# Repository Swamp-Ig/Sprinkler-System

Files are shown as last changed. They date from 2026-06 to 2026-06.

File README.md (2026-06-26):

# 6-Zone WiFi Sprinkler Controller

A custom PCB for controlling up to six 24 VAC irrigation solenoid valves via WiFi, using an ESP32 and ESPHome with native Home Assistant integration.

## Features

- **6 independent zones** — each zone switches a 24 VAC solenoid valve via an Omron G5LE-1 relay
- **WiFi control** — ESP32-WROOM-32U with external U.FL antenna connector
- **Home Assistant integration** — ESPHome firmware; zones appear as switch entities
- **Onboard power supply** — HLK-PM01 AC-DC module (mains → 5 V); AMS1117-3.3 regulator (5 V → 3.3 V for ESP32)
- **Relay isolation** — ULN2803A Darlington array isolates ESP32 GPIOs from relay coil drive current
- **Protected design** — varistors on each zone output and across the mains input and transformer primary (RV1/RV2), time-delay fuses on the mains and 24 VAC supplies, per-zone RC snubbers, and an optocoupler-isolated 24 VAC rail sense

## ⚠️ Safety

> **This board carries mains voltage (Line and Neutral) on the PCB.**  
> The HLK-PM01 module is connected directly to mains. The 24 VAC solenoid rail is transformer-isolated but still carries AC voltage.

- Do **not** touch or probe the board while it is powered.
- The enclosure **must** be non-conductive and fully closed before applying mains power.
- All mains wiring must comply with local electrical codes. Use appropriately rated cable and terminals.
- The external transformer must be safety-rated (UL, CE, or equivalent) for your locale.
- Replace fuses only with the specified ratings — see the BOM below.

See [Assembly Notes](docs/assembly.md) for enclosure requirements and conformal coating instructions.

## How It Works

The controller has three linked paths: logic power, 24 VAC valve power, and relay control.

**Logic power:** Mains → F1 → HLK-PM01 → 5 V → AMS1117-3.3 → 3.3 V → ESP32 + logic

**24 VAC path:** Mains → F1 → G3MB-202P SSR (K1, GPIO16) → J2 → external transformer → J3 → F2 → zone relays (K20–K25) → solenoids

**Control:** ESP32 GPIO17–23 → ULN2803A → relay coils K20–K25 → zone outputs J20–J25

When a zone is activated, the ESP32 first enables the 24 VAC rail (K1), then drives the selected relay through the ULN2803A. The ULN2803A acts as a low-side driver, keeping ESP32 GPIO current low while switching the 24 VAC solenoid load through the relay contacts.

## Bill of Materials

| Ref | Component | Value / Part No. | Notes |
|-----|---|---|---|
| U4 | ESP32 module | ESP32-WROOM-32U | External antenna (U.FL) |
| U3 | AC-DC module | HLK-PM01 | 100–240 VAC in, 5 V / 600 mA out |
| U1 | LDO regulator | AMS1117-3.3 | SOT-223 |
| U2 | Optocoupler | EL817 | Isolates the 24 VAC rail sense |
| U5 | Darlington array | ULN2803A | SOIC-18 |
| K1 | Solid-state relay | Omron G3MB-202P | Gates the 24 VAC solenoid rail (GPIO16) |
| K20–K25 | Relay ×6 | Omron G5LE-1 | SPDT, 5 V coil, 10 A / 250 VAC contacts |
| RV20–RV25 | Varistor ×6 | 68 V | Surge protection, one per zone output |
| RV1 | Varistor | 10D471K (275 VAC) | Across mains L–N input, after F1 |
| RV2 | Varistor | 10D471K (275 VAC) | Across K1 SSR output / transformer primary |
| F1 | Fuse | **T1A** (time-delay) | Mains supply — slow-blow for transformer/HLK inrush |
| F2 | Fuse | **T2A** (time-delay) | 24 VAC supply — slow-blow for solenoid inrush |
| D1 | Diode | 1N4148 (0805) | 24 VAC rail sense |
| C5 | Capacitor | 220 µF / ≥10 V | 5 V rail bulk reservoir (THT radial) |
| C1, C7 | SMD capacitors | 10 µF | Supply filtering |
| C2, C3 | SMD capacitors | 22 µF | Supply filtering / sense |
| C4, C6, C20–C25 | SMD capacitors | 100 nF | ESP32 VDD (C4), EN reset (C6), zone snubbers (C20–C25) |
| R1, R3, R5, R6, R8, R10, R11 | SMD resistors | 10 kΩ | Sense, pull-ups, pull-downs |
| R2, R9, R12–R14 | SMD resistors | 4.7 kΩ | Sense, LED series, I²C pull-ups |
| R4, R7 | SMD resistors | 470 Ω | EN/BOOT switch series |
| R20–R25 | SMD resistors | 100 Ω | Zone snubber series |
| LED1, LED2 | LED ×2 | 0805 | IO2 status / power |
| SW1, SW2 | Tactile switch ×2 | — | EN (reset) / BOOT |
| J1 | Screw terminal | Phoenix PT 1,5/3-5.0 (3-pin, 5.0 mm) | Mains input — must be mains-rated |
| J2 | Screw terminal | 2-pin, 5.0 mm | 240 VAC output to transformer primary |
| J3, J20–J25 | Pluggable terminal ×7 | KF2EDG-style, 2-pin | 24 VAC — J3 transformer in, J20–J25 zone outputs |
| XFMR | Transformer (external) | 240 VAC → 24 VAC, ≥50 VA, safety-rated | Size for zones × ~8 VA each |

See [`manufacturing/bom/bom.csv`](manufacturing/bom/bom.csv) for the full BOM with quantities and footprints.

## Reference

- [Wiring & GPIO](docs/wiring.md) — connector pinouts and GPIO assignments
- [ESPHome Configuration](docs/esphome.md) — full firmware config, fault detection, and optional pump relay setup
- [Assembly Notes](docs/assembly.md) — step-by-step build and commissioning guide

## Project Structure

```
Sprinkler System.kicad_pro    ← KiCad project file
Sprinkler System.kicad_sch    ← Schematic
Sprinkler System.kicad_pcb    ← PCB layout
Sprinkler System.pretty/      ← Custom footprints and 3D models
symbols/                       ← Custom symbol library (G3MB-202P)
manufacturing/
  gerbers/                     ← Gerber files for PCB fabrication
  drill/                       ← Excellon drill files
  pos/                         ← Pick-and-place centroid files
  bom/bom.csv                  ← Bill of materials
docs/
  schematic.pdf                ← Schematic PDF
  pcb.pdf                      ← PCB layer PDF
  board.step                   ← 3D STEP model
  wiring.md                    ← Connector and GPIO reference
  esphome.md                   ← ESPHome firmware configuration
  assembly.md                  ← Build and commissioning guide
.githooks/pre-commit           ← Auto-exports fabrication outputs on commit
setup / setup.ps1              ← One-time dev environment setup
release / release.ps1          ← Tag a release version
```

## Developing

### First-time setup

```powershell
.\setup.ps1
```

Configures the git hook path and verifies `kicad-cli` is available. Use `./setup` in Git Bash / WSL.

### Fabrication exports

Gerbers, drill files, PDFs, BOM, netlist, and STEP are regenerated automatically by the pre-commit hook whenever `Sprinkler System.kicad_pcb` or `Sprinkler System.kicad_sch` are staged. No manual export step is needed.

Run DRC and ERC from within KiCad before committing — fix all errors before submitting to a board house.

### Releasing

```powershell
.\release.ps1 v1.1.0
```

Stamps the schematic and PCB title blocks with the version and date, commits (triggering a fresh fabrication export), and creates the git tag. Use `./release v1.1.0` in Git Bash / WSL. Then push:

```powershell
git push && git push origin v1.1.0
```

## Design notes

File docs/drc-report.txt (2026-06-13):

** Drc report for Sprinkler System.kicad_pcb **
** Created on 2026-06-13T18:46:50 **
** Report includes: Errors, Warnings **

** Found 0 DRC violations **

** Found 0 unconnected pads **

** Found 0 Footprint errors **

** Ignored checks **
    - None

** End of Report **

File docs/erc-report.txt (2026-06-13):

ERC report (2026-06-13T18:46:48, Encoding UTF8)
Report includes: Errors, Warnings

***** Sheet /

 ** ERC messages: 0  Errors 0  Warnings 0

 ** Ignored checks:
    - Input Power pin not driven by any Output Power pins
    - Four connection points are joined together
    - SPICE model issue
    - Symbol doesn't match copy in library
    - Footprint link issue

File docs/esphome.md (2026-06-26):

# ESPHome Configuration

Flash the ESP32 via the J5 (UART0) header before installing the board in an enclosure. Add your secrets to `secrets.yaml`.

## Base Configuration (6 zones, no pump)

```yaml
esphome:
  name: sprinkler
  friendly_name: Sprinkler Controller

esp32:
  board: esp32dev

wifi:
  ssid: !secret wifi_ssid
  password: !secret wifi_password

api:
  encryption:
    key: !secret api_key

ota:
  - platform: esphome
    password: !secret ota_password

i2c:
  sda: GPIO5
  scl: GPIO4
  scan: true

globals:
  - id: fault_latched
    type: bool
    restore_value: true
    initial_value: 'false'

switch:
  - platform: gpio
    id: supply_24v
    pin: GPIO16
    name: "24V Supply"
    internal: true        # managed by sprinkler component via valve_open_switch
    restore_mode: ALWAYS_OFF

  - platform: gpio
    id: zone_0
    pin: GPIO17
    name: "Zone 0"
    internal: true
    restore_mode: ALWAYS_OFF

  - platform: gpio
    id: zone_1
    pin: GPIO18
    name: "Zone 1"
    internal: true
    restore_mode: ALWAYS_OFF

  - platform: gpio
    id: zone_2
    pin: GPIO19
    name: "Zone 2"
    internal: true
    restore_mode: ALWAYS_OFF

  - platform: gpio
    id: zone_3
    pin: GPIO21
    name: "Zone 3"
    internal: true
    restore_mode: ALWAYS_OFF

  - platform: gpio
    id: zone_4
    pin: GPIO22
    name: "Zone 4"
    internal: true
    restore_mode: ALWAYS_OFF

  - platform: gpio
    id: zone_5
    pin: GPIO23
    name: "Zone 5"
    internal: true
    restore_mode: ALWAYS_OFF

sprinkler:
  - id: sprinkler
    main_switch: "Sprinkler System"
    auto_advance: true
    valve_open_switch: supply_24v    # turns 24 VAC rail on/off automatically
    valves:
      - valve_switch: zone_0
        enable_switch: "Enable Zone 0"
        run_duration: 300s
        name: "Zone 0"
      - valve_switch: zone_1
        enable_switch: "Enable Zone 1"
        run_duration: 300s
        name: "Zone 1"
      - valve_switch: zone_2
        enable_switch: "Enable Zone 2"
        run_duration: 300s
        name: "Zone 2"
      - valve_switch: zone_3
        enable_switch: "Enable Zone 3"
        run_duration: 300s
        name: "Zone 3"
      - valve_switch: zone_4
        enable_switch: "Enable Zone 4"
        run_duration: 300s
        name: "Zone 4"
      - valve_switch: zone_5
        enable_switch: "Enable Zone 5"
        run_duration: 300s
        name: "Zone 5"

button:
  - platform: template
    name: "Reset 24V Fault"
    entity_category: config
    on_press:
      - globals.set:
          id: fault_latched
          value: 'false'

binary_sensor:
  - platform: gpio
    name: "Button 0"
    pin:
      number: GPIO34
      mode: INPUT         # input-only pin — external 10k pull-down sets idle LOW
      inverted: false   # active-HIGH — button pulls to +3.3 V, 10k pull-down idles LOW
    id: button_0

  - platform: gpio
    name: "Button 1"
    pin:
      number: GPIO35
      mode: INPUT         # input-only pin — external 10k pull-down sets idle LOW
      inverted: false
    id: button_1

  - platform: gpio
    name: "Button 2"
    pin:
      number: GPIO32
      mode: INPUT
      inverted: false
    id: button_2

  - platform: gpio
    name: "Button 3"
    pin:
      number: GPIO33
      mode: INPUT
      inverted: false
    id: button_3

  - platform: gpio
    name: "24V Present"
    pin:
      number: GPIO25
      mode: INPUT
    id: sens_24v
    device_class: power
    entity_category: diagnostic

  - platform: template
    name: "24V Fault"
    id: fault_24v
    device_class: problem
    filters:
      - delayed_on: 1s    # allow transformer + RC filter to charge before flagging fault
    lambda: |-
      return id(supply_24v).state && !id(sens_24v).state;
    on_press:
      then:
        - globals.set:
            id: fault_latched
            value: 'true'
        - sprinkler.stop: sprinkler

  - platform: template
    name: "24V Fault Latched"
    id: fault_latched_sensor
    device_class: problem
    entity_category: diagnostic
    lambda: 'return id(fault_latched);'

# Stop the sprinkler immediately if it is started while a fault is latched
interval:
  - interval: 500ms
    then:
      - if:
          condition:
            lambda: 'return id(fault_latched) && id(sprinkler).is_running();'
          then:
            - sprinkler.stop: sprinkler
```

`restore_mode: ALWAYS_OFF` ensures all outputs are off on boot or after a power failure — valves never left open unintentionally.

The zone GPIO switches are marked `internal: true` so they don't appear as individual entities in Home Assistant — the `sprinkler` component exposes them as named valves instead. The **24V Supply** switch is also internal; `valve_open_switch: supply_24v` tells ESPHome to energise K1 (the 24 VAC SSR) automatically when the first valve opens and cut it after the last valve closes.

Adjust `run_duration` per zone as needed.

---

## 24 VAC Fault Detection

GPIO25 reads the `Sens_24V` net, driven by an **EL817 optocoupler (U2)** that isolates the logic from the 24 VAC rail. On the rail side, D1 (1N4148) half-wave rectifies the 24 VAC and R1 (10 kΩ) limits the EL817 LED current. On the logic side the EL817 transistor pulls `Sens_24V` toward 3.3 V, with R2 (4.7 kΩ) and C3 (22 µF) forming the load and smoothing filter. When the rail is live the pin reads HIGH; when F2 blows or the transformer is absent, C3 discharges through R2 and the pin falls to LOW within a few hundred milliseconds.

**Fault behaviour**: when `supply_24v` is `ON` but `sens_24v` is `OFF`, the `24V Fault` sensor fires. This latches the `fault_latched` global, immediately stops the sprinkler, and the 500 ms interval prevents it from restarting. The latch persists across power cycles (`restore_value: true`).

**To clear**: press the **Reset 24V Fault** button in Home Assistant (or via the ESPHome API) after the underlying cause is fixed (e.g. replace F2). Add a Home Assistant automation on `fault_latched_sensor` to alert when a fault is detected.

---

## Optional: Pump Relay

Zone 0 (J20 / GPIO17 / K20) can be repurposed as a pump relay, giving 5 irrigation zones (Zones 1–5) plus a pump. This is useful when a booster pump or pump start relay is needed to maintain pressure.

Both the 24V supply (K1 SSR) and the pump relay need to be active whenever a valve runs. A template switch combines them as the single `valve_open_switch`. Replace the `valve_open_switch` and `valves` sections as follows:

```yaml
switch:
  # zone_0 becomes the pump relay
  - platform: gpio
    id: pump_relay
    pin: GPIO17
    name: "Pump"
    internal: true
    restore_mode: ALWAYS_OFF

  # Template switch enables both 24V supply and pump relay together
  - platform: template
    id: valve_master
    optimistic: true
    turn_on_action:
      - switch.turn_on: supply_24v
      - switch.turn_on: pump_relay
    turn_off_action:
      - switch.turn_off: pump_relay
      - switch.turn_off: supply_24v

  # supply_24v and zone_1–zone_5 unchanged

sprinkler:
  - id: sprinkler
    main_switch: "Sprinkler System"
    auto_advance: true
    valve_open_switch: valve_master   # enables both 24V rail and pump
    valves:
      # zone_0 removed — now the pump relay
      - valve_switch: zone_1
        enable_switch: "Enable Zone 1"
        run_duration: 300s
        name: "Zone 1"
      # ... zone_2 through zone_5
```

For precise pump start/stop delays (to control sequencing and water hammer), see the [ESPHome Sprinkler Controller documentation](https://esphome.io/components/sprinkler.html).

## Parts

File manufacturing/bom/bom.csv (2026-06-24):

Refs | Value | Footprint | Qty | DNP
C1 | 10u | Capacitor_SMD:C_0805_2012Metric_Pad1.18x1.45mm_HandSolder | 1
C2 | 22u | Capacitor_SMD:C_0805_2012Metric_Pad1.18x1.45mm_HandSolder | 1
C3 | 22u | Capacitor_SMD:C_0805_2012Metric_Pad1.18x1.45mm_HandSolder | 1
C4 | 100n | Capacitor_SMD:C_0805_2012Metric_Pad1.18x1.45mm_HandSolder | 1
C5 | 220u | Capacitor_THT:CP_Radial_D6.3mm_P2.50mm | 1
C6 | 100n | Capacitor_SMD:C_0805_2012Metric_Pad1.18x1.45mm_HandSolder | 1
C7 | 10u | Capacitor_SMD:C_0805_2012Metric_Pad1.18x1.45mm_HandSolder | 1
C20 | 100n | Capacitor_SMD:C_0805_2012Metric_Pad1.18x1.45mm_HandSolder | 1
C21 | 100n | Capacitor_SMD:C_0805_2012Metric_Pad1.18x1.45mm_HandSolder | 1
C22 | 100n | Capacitor_SMD:C_0805_2012Metric_Pad1.18x1.45mm_HandSolder | 1
C23 | 100n | Capacitor_SMD:C_0805_2012Metric_Pad1.18x1.45mm_HandSolder | 1
C24 | 100n | Capacitor_SMD:C_0805_2012Metric_Pad1.18x1.45mm_HandSolder | 1
C25 | 100n | Capacitor_SMD:C_0805_2012Metric_Pad1.18x1.45mm_HandSolder | 1
D1 | 1N4148 | Diode_SMD:D_0805_2012Metric_Pad1.15x1.40mm_HandSolder | 1
F1 | T1A | Sprinkler System:Fuseholder_5x20mm_15mm_Pins | 1
F2 | T2A | Sprinkler System:Fuseholder_5x20mm_15mm_Pins | 1
J1 | Main_Supply | TerminalBlock_Phoenix:TerminalBlock_Phoenix_PT-1,5-3-5.0-H_1x03_P5.00mm_Horizontal | 1
J2 | XFMR_Out | TerminalBlock_Phoenix:TerminalBlock_Phoenix_PT-1,5-2-5.0-H_1x02_P5.00mm_Horizontal | 1
J3 | XFMR_In | Connector_Phoenix_MC:PhoenixContact_MC_1,5_2-G-3.81_1x02_P3.81mm_Horizontal | 1
J4 | Conn_Button | Connector_JST:JST_XH_B6B-XH-A_1x06_P2.50mm_Vertical | 1
J5 | UART0 | Connector_JST:JST_XH_B4B-XH-A_1x04_P2.50mm_Vertical | 1
J6 | I2C | Connector_JST:JST_XH_B4B-XH-A_1x04_P2.50mm_Vertical | 1
J20 | Station_0 | Connector_Phoenix_MC:PhoenixContact_MC_1,5_2-G-3.81_1x02_P3.81mm_Horizontal | 1
J21 | Station_1 | Connector_Phoenix_MC:PhoenixContact_MC_1,5_2-G-3.81_1x02_P3.81mm_Horizontal | 1
J22 | Station_2 | Connector_Phoenix_MC:PhoenixContact_MC_1,5_2-G-3.81_1x02_P3.81mm_Horizontal | 1
J23 | Station_3 | Connector_Phoenix_MC:PhoenixContact_MC_1,5_2-G-3.81_1x02_P3.81mm_Horizontal | 1
J24 | Station_4 | Connector_Phoenix_MC:PhoenixContact_MC_1,5_2-G-3.81_1x02_P3.81mm_Horizontal | 1
J25 | Station_5 | Connector_Phoenix_MC:PhoenixContact_MC_1,5_2-G-3.81_1x02_P3.81mm_Horizontal | 1
JP1 | I2C_VCC | Jumper:SolderJumper-3_P1.3mm_Bridged12_RoundedPad1.0x1.5mm_NumberLabels | 1
K1 | G3MB-202P | Sprinkler System:RELAY_G3MB-202P | 1
K20 | G5LE-1-DC5 | Relay_THT:Relay_SPDT_Omron-G5LE-1 | 1
K21 | G5LE-1-DC5 | Relay_THT:Relay_SPDT_Omron-G5LE-1 | 1
K22 | G5LE-1-DC5 | Relay_THT:Relay_SPDT_Omron-G5LE-1 | 1
K23 | G5LE-1-DC5 | Relay_THT:Relay_SPDT_Omron-G5LE-1 | 1
K24 | G5LE-1-DC5 | Relay_THT:Relay_SPDT_Omron-G5LE-1 | 1
K25 | G5LE-1-DC5 | Relay_THT:Relay_SPDT_Omron-G5LE-1 | 1
LED1 | IO2 | LED_SMD:LED_0805_2012Metric_Pad1.15x1.40mm_HandSolder | 1
LED2 | PWR | LED_SMD:LED_0805_2012Metric_Pad1.15x1.40mm_HandSolder | 1
R1 | 10k | Resistor_SMD:R_0805_2012Metric_Pad1.20x1.40mm_HandSolder | 1
R2 | 4k7 | Resistor_SMD:R_0805_2012Metric_Pad1.20x1.40mm_HandSolder | 1
R3 | 10k | Resistor_SMD:R_0805_2012Metric_Pad1.20x1.40mm_HandSolder | 1
R4 | 470 | Resistor_SMD:R_0805_2012Metric_Pad1.20x1.40mm_HandSolder | 1
R5 | 10k | Resistor_SMD:R_0805_2012Metric_Pad1.20x1.40mm_HandSolder | 1
R6 | 10k | Resistor_SMD:R_0805_2012Metric_Pad1.20x1.40mm_HandSolder | 1
R7 | 470 | Resistor_SMD:R_0805_2012Metric_Pad1.20x1.40mm_HandSolder | 1
R8 | 10k | Resistor_SMD:R_0805_2012Metric_Pad1.20x1.40mm_HandSolder | 1
R9 | 4k7 | Resistor_SMD:R_0805_2012Metric_Pad1.20x1.40mm_HandSolder | 1
R10 | 10k | Resistor_SMD:R_0805_2012Metric_Pad1.20x1.40mm_HandSolder | 1
R11 | 10k | Resistor_SMD:R_0805_2012Metric_Pad1.20x1.40mm_HandSolder | 1
R12 | 4k7 | Resistor_SMD:R_0805_2012Metric_Pad1.20x1.40mm_HandSolder | 1
R13 | 4k7 | Resistor_SMD:R_0805_2012Metric_Pad1.20x1.40mm_HandSolder | 1
R14 | 4k7 | Resistor_SMD:R_0805_2012Metric_Pad1.20x1.40mm_HandSolder | 1
R20 | 100 | Resistor_SMD:R_0805_2012Metric_Pad1.20x1.40mm_HandSolder | 1
R21 | 100 | Resistor_SMD:R_0805_2012Metric_Pad1.20x1.40mm_HandSolder | 1
R22 | 100 | Resistor_SMD:R_0805_2012Metric_Pad1.20x1.40mm_HandSolder | 1
R23 | 100 | Resistor_SMD:R_0805_2012Metric_Pad1.20x1.40mm_HandSolder | 1
R24 | 100 | Resistor_SMD:R_0805_2012Metric_Pad1.20x1.40mm_HandSolder | 1
R25 | 100 | Resistor_SMD:R_0805_2012Metric_Pad1.20x1.40mm_HandSolder | 1
RV1 | 10D471K | Varistor:RV_Disc_D12mm_W4mm_P7.5mm | 1
RV2 | 10D471K | Varistor:RV_Disc_D12mm_W4mm_P7.5mm | 1
RV20 | 68V | Varistor:RV_Disc_D15.5mm_W5.4mm_P7.5mm | 1
RV21 | 68V | Varistor:RV_Disc_D15.5mm_W5.4mm_P7.5mm | 1
RV22 | 68V | Varistor:RV_Disc_D15.5mm_W5.4mm_P7.5mm | 1
RV23 | 68V | Varistor:RV_Disc_D15.5mm_W5.4mm_P7.5mm | 1
RV24 | 68V | Varistor:RV_Disc_D15.5mm_W5.4mm_P7.5mm | 1
RV25 | 68V | Varistor:RV_Disc_D15.5mm_W5.4mm_P7.5mm | 1
SW1 | EN | Button_Switch_SMD:SW_Push_SPST_NO_Alps_SKRK | 1
SW2 | BOOT | Button_Switch_SMD:SW_Push_SPST_NO_Alps_SKRK | 1
TP1 | Gnd | TestPoint:TestPoint_Pad_D1.5mm | 1
TP2 | 5V | TestPoint:TestPoint_Pad_D1.5mm | 1
TP3 | 3v3 | TestPoint:TestPoint_Pad_D1.5mm | 1
U1 | AMS1117-3.3 | Package_TO_SOT_SMD:SOT-223-3_TabPin2 | 1
U2 | EL817 | Package_SO:SOP-4_3.8x4.1mm_P2.54mm | 1
U3 | HLK-PM01 | Converter_ACDC:Converter_ACDC_Hi-Link_HLK-PMxx | 1
U4 | ESP32-WROOM-32U | RF_Module:ESP32-WROOM-32U | 1
U5 | ULN2803A | Package_SO:SOIC-18W_7.5x11.6mm_P1.27mm | 1

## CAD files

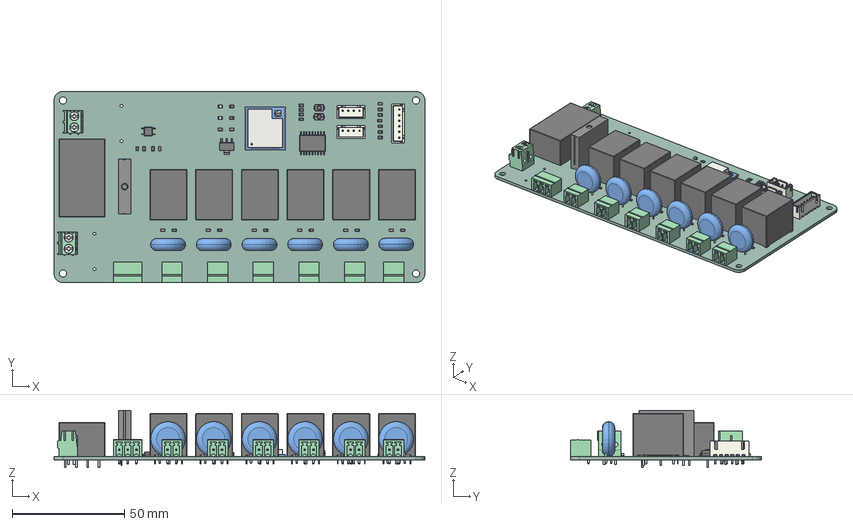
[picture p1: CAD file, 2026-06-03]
docs/board.step
165.0 x 85.0 x 25.4 mm
MC_01x02_G_3_81mm x 6
C_0805_2012Metric x 10
R_0805_2012Metric x 20
JST_B4B_XH_A x 2
LED_0805_2012Metric x 2
TerminalBlock_Phoenix_PT-1,5-2-5.0-H_1x02_P5.00mm_Horizontal x 2
Converter_ACDC_Hi-Link_HLK-PMxx
RV_Disc_D155mm_W54mm_P75mm x 6
SOT-223
Relay_SPDT_Omron-G5LE-1 x 6
SW_Push_SPST_NO_Alps_SKRK x 2
G3MB-202P-DC12
SOIC-18W_7.5x11.6mm_P1.27mm
D_0805
ESP32-WROOM-32U
MC_01x03_G_3_81mm
SOP-4_3.8x4.1mm_P2.54mm
JST_B6B_XH_A
Sprinkler System_PCB

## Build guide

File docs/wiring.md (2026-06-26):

# Wiring & GPIO Reference

## Connectors

### J1 — Main Supply
3-pin 5.0 mm Phoenix PT-series terminal block (PT 1,5/3-5.0, mains-rated), bottom-left of board. Mains input; also feeds J2 to supply the external transformer primary.

| Pin | Signal | Connect to |
|-----|---|---|
| 1 | GND / Earth | Safety earth |
| 2 | Live | Mains live (240 VAC) |
| 3 | Neutral | Mains neutral |

### J2 — XFMR Out
2-pin screw terminal. 240 VAC output from the board to the **primary** of an external step-down transformer.

| Pin | Signal |
|-----|---|
| 1 | Live (switched to transformer primary via K1 SSR) |
| 2 | Neutral |

### J3 — XFMR In
2-pin pluggable terminal (KF2EDG-style). 24 VAC input from the **secondary** of the external transformer — the solenoid supply rail.

| Pin | Signal |
|-----|---|
| 1 | 24 VAC hot |
| 2 | 24 VAC common / return |

Use a safety-rated 240 VAC → 24 VAC transformer. VA rating: number of simultaneously-running valves × ~8 VA each, minimum 50 VA recommended.

### Zone Terminals — J20–J25
2-pin pluggable terminal connectors (KF2EDG-style), one per zone. Each has a switched 24 VAC output and a 24 VAC common. Polarity does not matter for standard solenoids.

| Terminal | Connector | GPIO | Relay |
|---|---|---|---|
| Station 0 | J20 | GPIO 17 | K20 |
| Station 1 | J21 | GPIO 18 | K21 |
| Station 2 | J22 | GPIO 19 | K22 |
| Station 3 | J23 | GPIO 21 | K23 |
| Station 4 | J24 | GPIO 22 | K24 |
| Station 5 | J25 | GPIO 23 | K25 |

Station 0 (J20/GPIO17/K20) can optionally be wired to a pump relay instead of a solenoid — see [ESPHome Configuration](esphome.md#optional-pump-relay).

### J4 — Button Inputs
6-pin JST XH. Four digital inputs with 10 kΩ pull-**down** resistors to GND (R5, R8, R10, R11). Pin 2 supplies 3.3 V; a button wired from a GPIO pin to pin 2 reads **active-HIGH** (HIGH while pressed). GPIO34 and GPIO35 are input-only pins (no internal pull — the external 10 kΩ resistors set their idle level).

| Pin | Signal |
|-----|---|
| 1 | GND |
| 2 | +3.3 V |
| 3 | Button 0 (GPIO34) |
| 4 | Button 1 (GPIO35) |
| 5 | Button 2 (GPIO32) |
| 6 | Button 3 (GPIO33) |

Wire each button between pin 2 (+3.3 V) and the desired button pin.

If more than four inputs are needed, GPIO34 (Button 0, pin 3) can be wired as a resistor ladder to give 16+ combinations on a single ADC input. GPIO34 is preferred for this as it is input-only with no competing functions. See the [ESPHome ADC documentation](https://esphome.io/components/sensor/adc.html).

### J5 — UART0
4-pin JST XH. For programming and serial debug. Connect a 5 V USB-to-UART adapter here — the adapter's 5 V powers U1 (AMS1117-3.3) and the ESP32 without needing mains. **Power from one source at a time** — do not connect the UART adapter's 5 V while the board is also running from mains.

| Pin | Signal |
|-----|---|
| 1 | GND |
| 2 | 5 V |
| 3 | RX (IO3) |
| 4 | TX (IO1) |

### J6 — I²C
4-pin JST XH. General-purpose I²C bus with onboard 4.7 kΩ pull-ups (R13/R14 to 3.3 V). Suitable for displays, sensors, or expanders.

| Pin | Signal |
|-----|---|
| 1 | GND |
| 2 | VCC — selectable by JP1: **3.3 V (default)** or 5 V |
| 3 | SDA (GPIO5) |
| 4 | SCL (GPIO4) |

**JP1 supply jumper** (back side, near J6): ships bridged 1–2 = **3.3 V**. To power a 5 V peripheral, cut the 1–2 link and bridge 2–3. Note the SDA/SCL pull-ups remain on 3.3 V — if a 5 V peripheral drives the lines to 5 V, add a level shifter (e.g. TCA9406) to protect the ESP32 pins.

---

## GPIO Pinout

| GPIO | Function | Notes |
|---|---|---|
| 0 | BOOT | Pull low to enter bootloader |
| 1 | UART TX | J5 — programming / debug |
| 2 | Status LED | Boot-mode indicator |
| 3 | UART RX | J5 — programming / debug |
| 4 | I²C SCL | J6 — onboard 4.7 kΩ pull-up (R14) |
| 5 | I²C SDA | J6 — onboard 4.7 kΩ pull-up (R13) |
| 16 | 24V_On | Enables 24 VAC supply via K1 (G3MB-202P SSR) |
| 17 | Zone 0 | → ULN2803A → K20 relay (or pump relay — optional) |
| 18 | Zone 1 | → ULN2803A → K21 relay |
| 19 | Zone 2 | → ULN2803A → K22 relay |
| 21 | Zone 3 | → ULN2803A → K23 relay |
| 22 | Zone 4 | → ULN2803A → K24 relay |
| 23 | Zone 5 | → ULN2803A → K25 relay |
| 25 | 24V sense | EL817 optocoupler output — HIGH when 24 VAC rail is live |
| 32 | Button 2 | J4 pin 5, 10 kΩ pull-down (R5) — active-HIGH |
| 33 | Button 3 | J4 pin 6, 10 kΩ pull-down (R8) — active-HIGH |
| 34 | Button 0 | J4 pin 3, 10 kΩ pull-down (R10) — active-HIGH, input-only |
| 35 | Button 1 | J4 pin 4, 10 kΩ pull-down (R11) — active-HIGH, input-only |

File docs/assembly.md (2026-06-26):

# Assembly Notes

1. **SMD first** — solder U1 (AMS1117, SOT-223), U2 (EL817), U5 (ULN2803A, SOIC-18), bypass capacitors, and resistors before installing through-hole parts. JP1 (I²C supply jumper) is on the **back** side.

2. **HLK-PM01 (U3)** — the module solders via its 4 pins. Ensure solid joints; this carries mains current.

3. **Relay orientation** — G5LE-1 relays are polarised. Match the notch on pin 1 to the PCB silkscreen indicator.

4. **ULN2803A (U5)** — SOIC-18 surface-mount package; cannot be socketed. Take care with orientation — pin 1 dot to silkscreen marker.

5. **ESP32 antenna clearance** — route the U.FL antenna cable away from the PCB and metal enclosure walls; keep it clear of high-voltage traces.

6. **Fuse holders** — use 5×20 mm holders per the footprint. Insert fuses after all soldering is complete.

7. **Bench test & flash** — before applying mains, connect a 5 V USB-to-UART adapter to J5 (UART0). The adapter's 5 V pin powers U1 (AMS1117-3.3), which supplies 3.3 V to the ESP32. Verify 3.3 V is present on the low-voltage rail with a multimeter. Hold BOOT (GPIO0 low) and press EN to enter the bootloader, then flash ESPHome via `esphome run`. Confirm the device connects to WiFi and appears in Home Assistant. Disconnect J5.

8. **Mains power-on (no transformer)** — leave J5 disconnected. Apply mains via J1. Verify 5 V at U3 output and 3.3 V at U1 output with a multimeter. Confirm the ESP32 boots and reconnects to Home Assistant. Disconnect mains.

9. **Full commissioning** — wire the transformer between J2 (primary) and J3 (secondary). Connect solenoids to the zone terminals. Apply mains and test each zone from Home Assistant.

---

## Enclosure

This board must be installed in a suitable enclosure. Since it is likely to be installed outdoors near irrigation equipment:

- **IP65 minimum** — dust-tight and protected against water jets. IP66 or better if there is any chance of direct spray or hosing down.
- Use a **non-conductive (plastic) enclosure** — metal enclosures require additional insulation between the mains terminals and the enclosure wall.
- All cable entry points must be sealed with appropriate **cable glands** rated for the enclosure IP class.
- Mount the enclosure **vertically** with cable entries facing down to prevent water pooling at the glands.

---

## Conformal Coating

Even inside a sealed enclosure, condensation can form on the PCB during temperature cycling. Apply conformal coating after final assembly and testing:

- **Mask before coating**: the mains/transformer terminals (J1–J3), pluggable zone connectors (J20–J25), fuse holders, the ESP32 U.FL connector, and the UART header (J5).
- Apply 2–3 thin coats of acrylic or silicone conformal coating to both sides of the PCB.
- Allow to fully cure before installing in the enclosure.

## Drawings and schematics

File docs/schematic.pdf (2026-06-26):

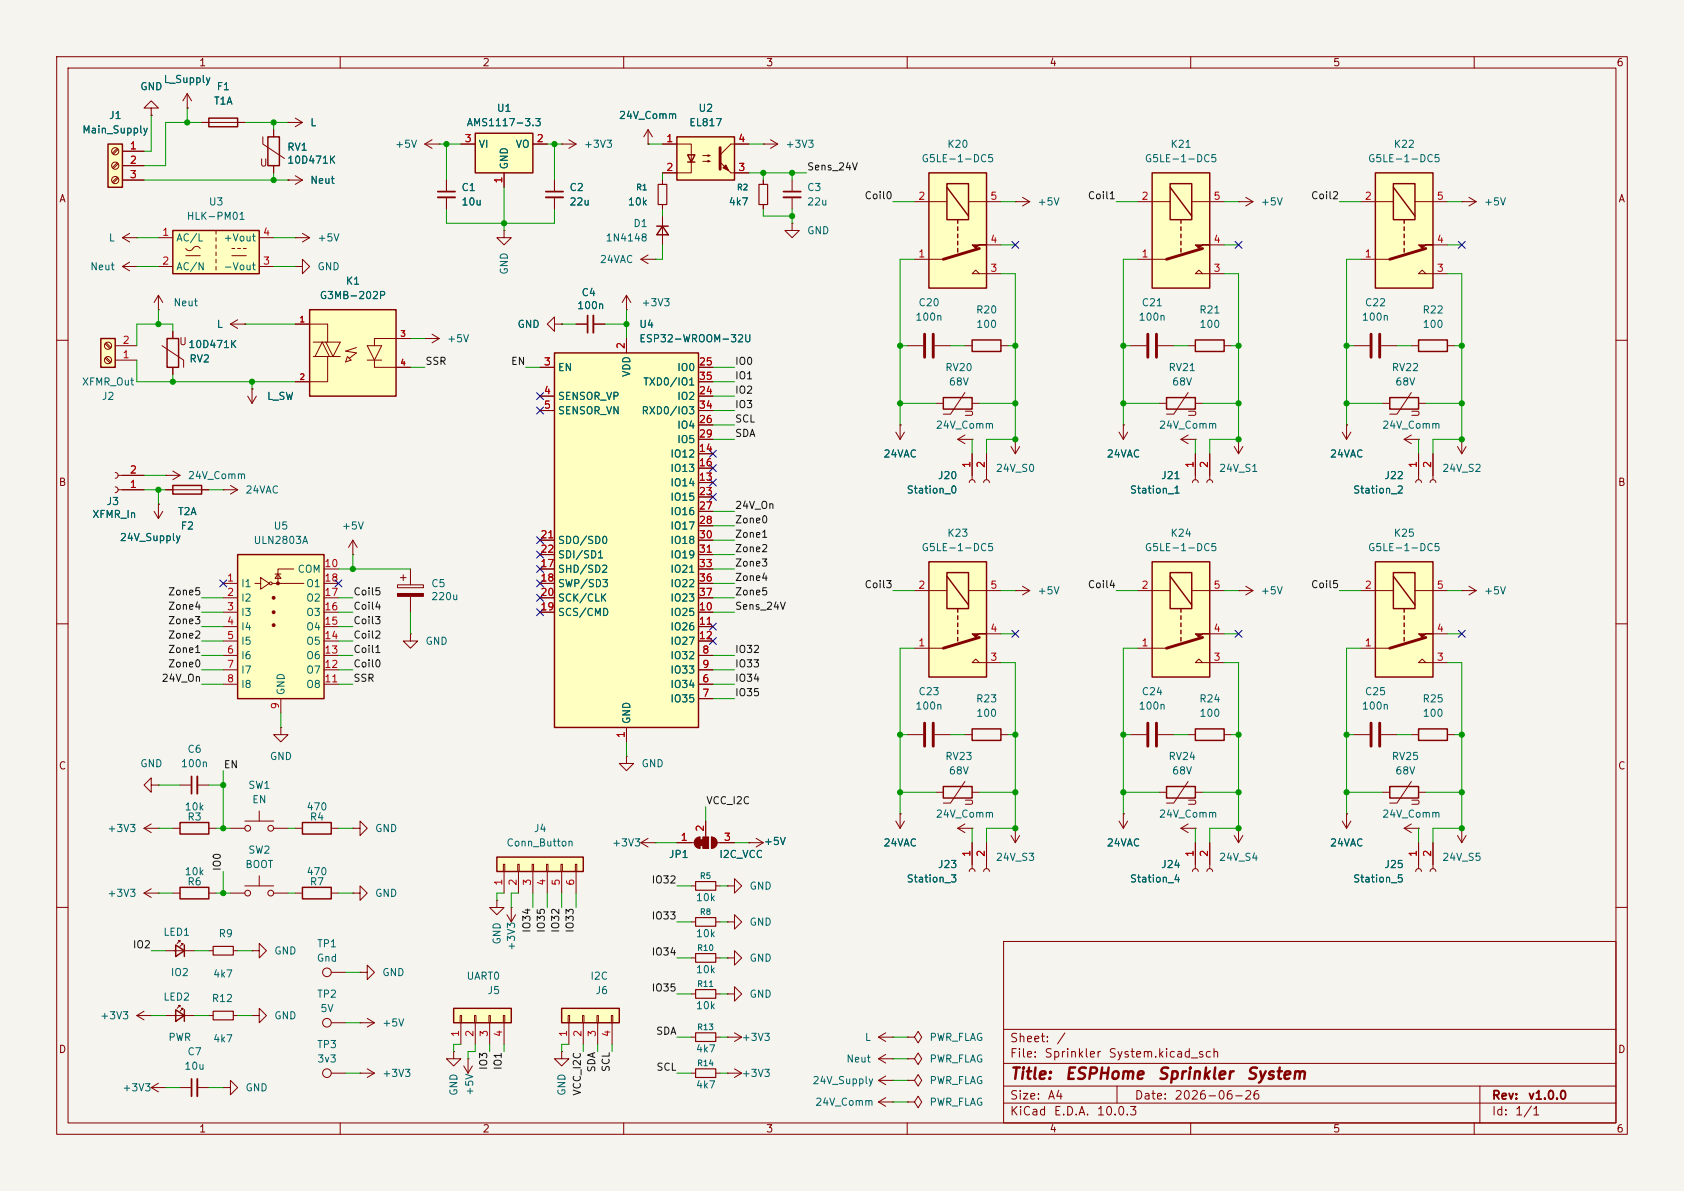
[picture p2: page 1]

Sheet: /
File: Sprinkler System.kicad_sch
Title: ESPHome Sprinkler System

Size: A4 | Rev: v1.0.0
KiCad E.D.A. 10.0.3 | Id: 1/1

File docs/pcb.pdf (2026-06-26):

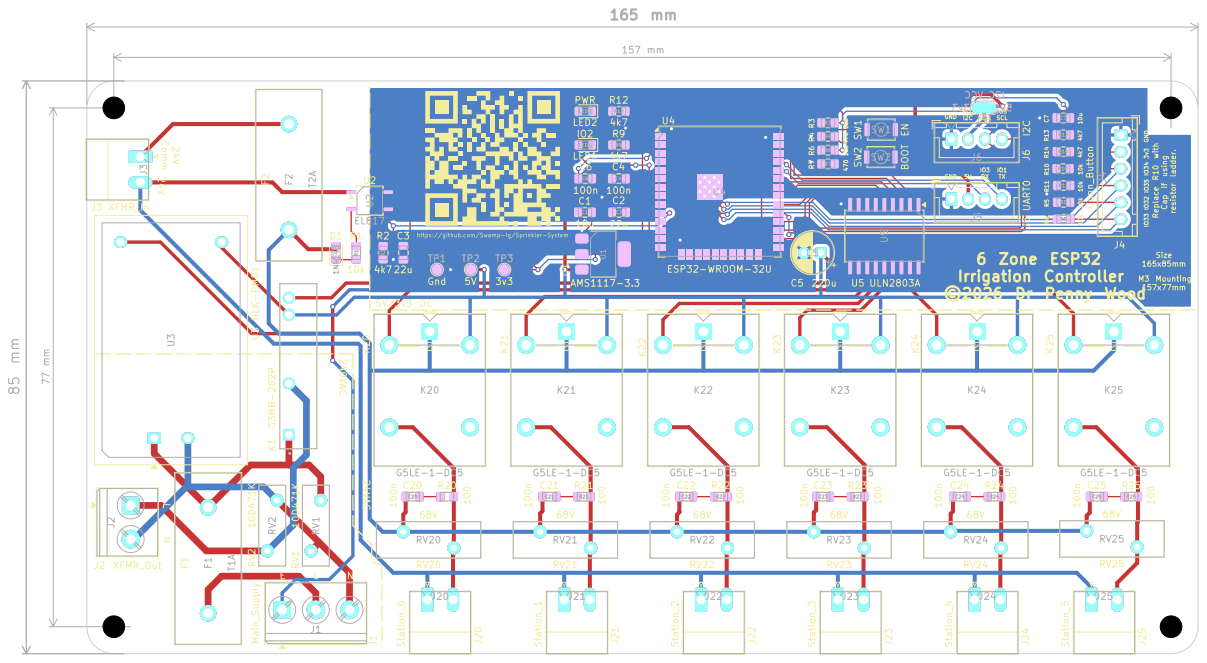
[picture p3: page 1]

SDA
M3 Mounting 157x77mm Replace R10 with Cap if using resistor ladder.

Sheet:
File: Sprinkler System.kicad_pcb
Title: ESPHome Sprinkler System

Size: A4 | Rev: v1.0.0
KiCad E.D.A. 10.0.3 | Id: 1/1

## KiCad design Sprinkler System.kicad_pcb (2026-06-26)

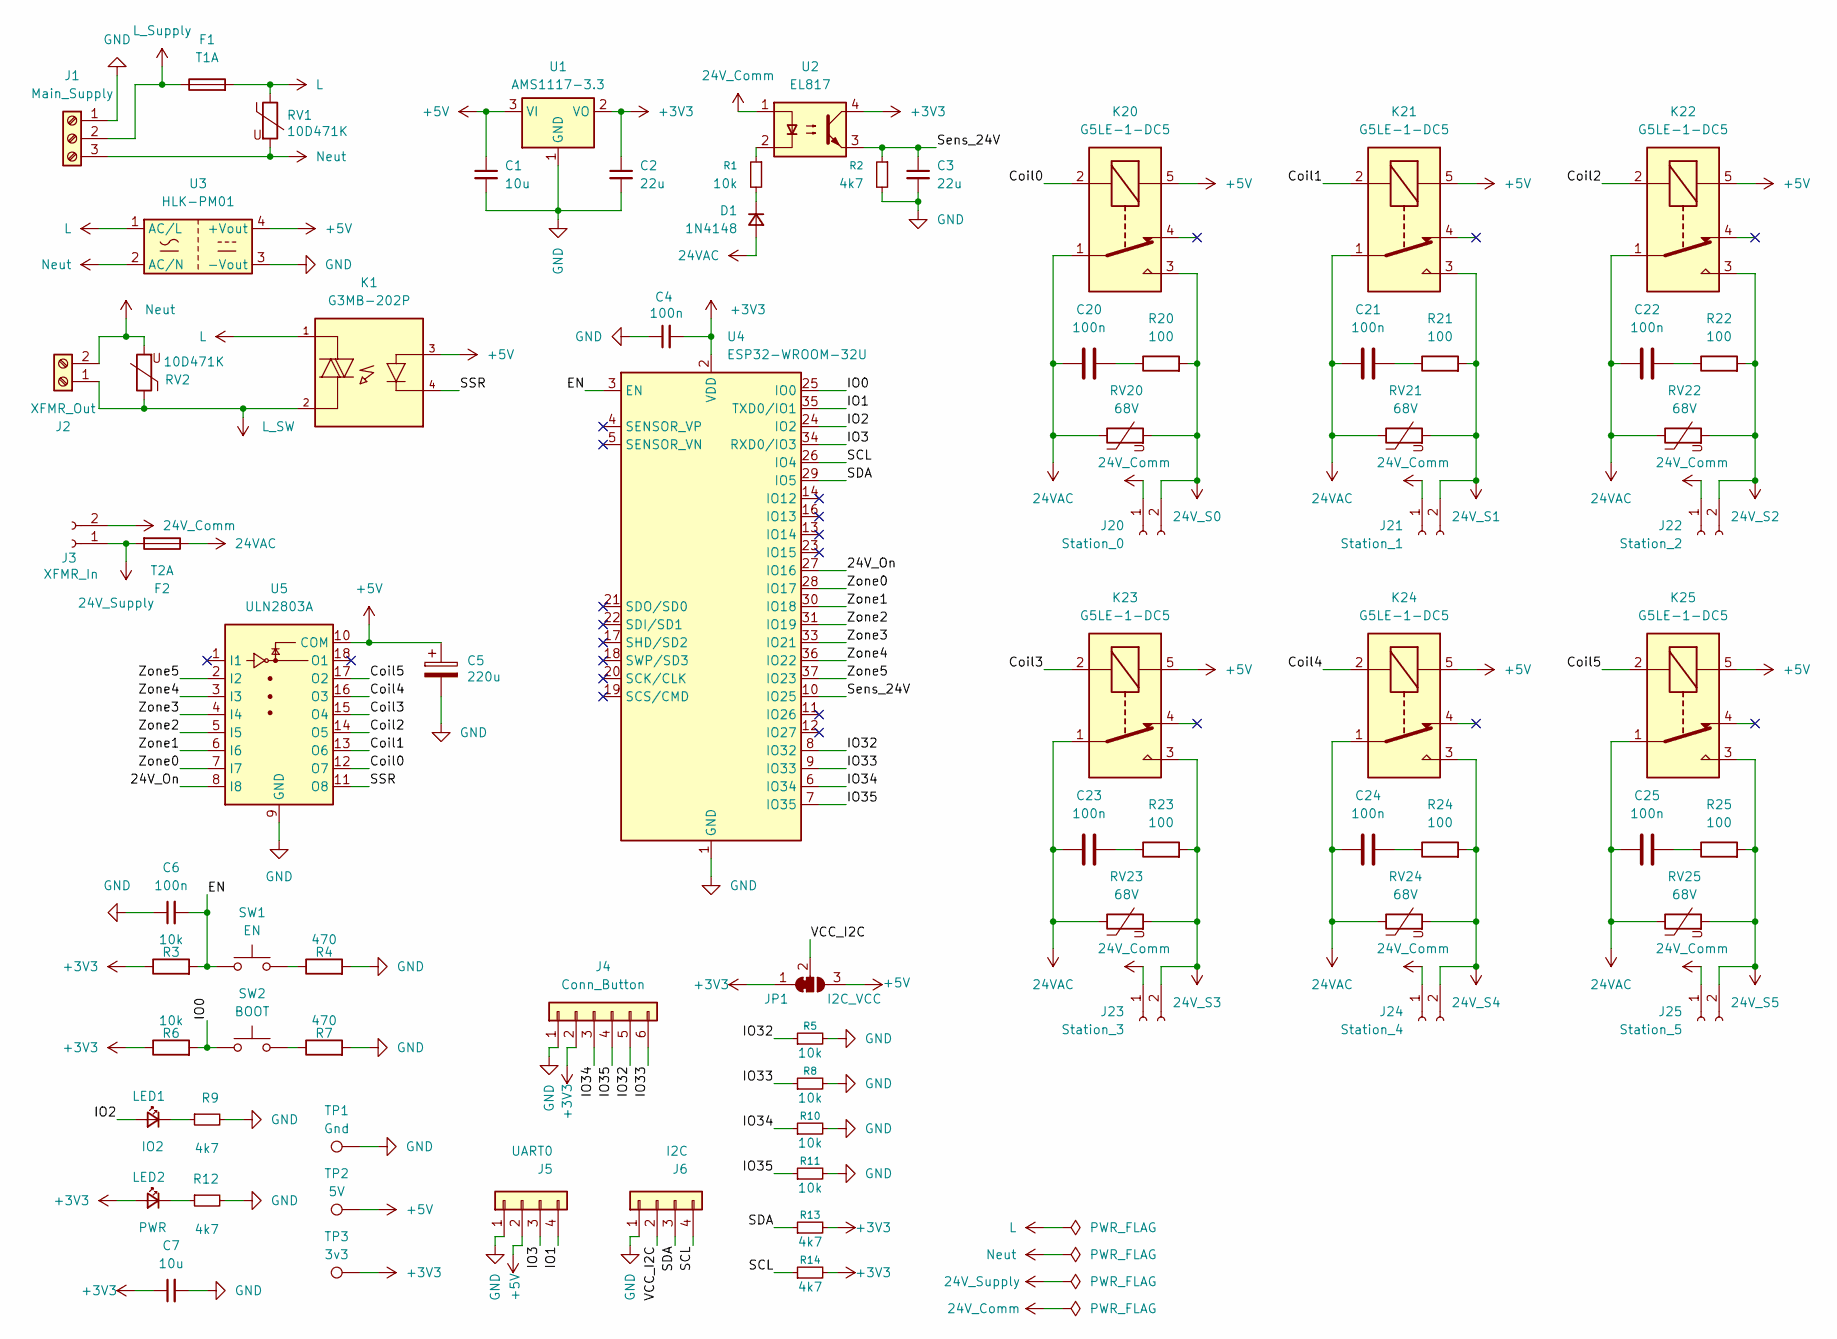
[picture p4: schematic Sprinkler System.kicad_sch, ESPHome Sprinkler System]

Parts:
C1, C7: 10u; C_0805_2012Metric_Pad1.18x1.45mm_HandSolder
C2, C3: 22u; C_0805_2012Metric_Pad1.18x1.45mm_HandSolder
C4, C6, C20, C21, C22, C23, C24, C25: 100n; C_0805_2012Metric_Pad1.18x1.45mm_HandSolder
C5: 220u; CP_Radial_D6.3mm_P2.50mm
D1: 1N4148; D_0805_2012Metric_Pad1.15x1.40mm_HandSolder
F1: T1A; Fuseholder_5x20mm_15mm_Pins
F2: T2A; Fuseholder_5x20mm_15mm_Pins
J1: Main_Supply; TerminalBlock_Phoenix_PT-1,5-3-5.0-H_1x03_P5.00mm_Horizontal
J2: XFMR_Out; TerminalBlock_Phoenix_PT-1,5-2-5.0-H_1x02_P5.00mm_Horizontal
J3: XFMR_In; PhoenixContact_MC_1,5_2-G-3.81_1x02_P3.81mm_Horizontal
J4: Conn_Button; JST_XH_B6B-XH-A_1x06_P2.50mm_Vertical
J5: UART0; JST_XH_B4B-XH-A_1x04_P2.50mm_Vertical
J6: I2C; JST_XH_B4B-XH-A_1x04_P2.50mm_Vertical
J20: Station_0; PhoenixContact_MC_1,5_2-G-3.81_1x02_P3.81mm_Horizontal
J21: Station_1; PhoenixContact_MC_1,5_2-G-3.81_1x02_P3.81mm_Horizontal
J22: Station_2; PhoenixContact_MC_1,5_2-G-3.81_1x02_P3.81mm_Horizontal
J23: Station_3; PhoenixContact_MC_1,5_2-G-3.81_1x02_P3.81mm_Horizontal
J24: Station_4; PhoenixContact_MC_1,5_2-G-3.81_1x02_P3.81mm_Horizontal
J25: Station_5; PhoenixContact_MC_1,5_2-G-3.81_1x02_P3.81mm_Horizontal
JP1: I2C_VCC; SolderJumper-3_P1.3mm_Bridged12_RoundedPad1.0x1.5mm_NumberL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
K1: G3MB-202P; RELAY_G3MB-202P; PARTREV 06/09
K20, K21, K22, K23, K24, K25: G5LE-1-DC5; Relay_SPDT_Omron-G5LE-1
LED1: IO2; LED_0805_2012Metric_Pad1.15x1.40mm_HandSolder
LED2: PWR; LED_0805_2012Metric_Pad1.15x1.40mm_HandSolder
R1, R3, R5, R6, R8, R10, R11: 10k; R_0805_2012Metric_Pad1.20x1.40mm_HandSolder
R2, R9, R12, R13, R14: 4k7; R_0805_2012Metric_Pad1.20x1.40mm_HandSolder
R4, R7: 470; R_0805_2012Metric_Pad1.20x1.40mm_HandSolder
R20, R21, R22, R23, R24, R25: 100; R_0805_2012Metric_Pad1.20x1.40mm_HandSolder
RV1, RV2: 10D471K; RV_Disc_D12mm_W4mm_P7.5mm
RV20, RV21, RV22, RV23, RV24, RV25: 68V; RV_Disc_D15.5mm_W5.4mm_P7.5mm
SW1: EN; SW_Push_SPST_NO_Alps_SKRK
SW2: BOOT; SW_Push_SPST_NO_Alps_SKRK
TP1: Gnd; TestPoint_Pad_D1.5mm
TP2: 5V; TestPoint_Pad_D1.5mm
TP3: 3v3; TestPoint_Pad_D1.5mm
U1: AMS1117-3.3; SOT-223-3_TabPin2
U2: EL817; SOP-4_3.8x4.1mm_P2.54mm
U3: HLK-PM01; Converter_ACDC_Hi-Link_HLK-PMxx
U4: ESP32-WROOM-32U
U5: ULN2803A; SOIC-18W_7.5x11.6mm_P1.27mm

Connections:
24VAC: C20.1, C21.1, C22.1, C23.1, C24.1, C25.1, D1.2 (A), F2.1, K20.1, K21.1, K22.1, K23.1, K24.1, K25.1, RV20.1, RV21.1, RV22.1, RV23.1, RV24.1, RV25.1
24V_Comm: J3.2, J20.1, J21.1, J22.1, J23.1, J24.1, J25.1, U2.1
24V_S0: J20.2, K20.3, R20.2, RV20.2
24V_S1: J21.2, K21.3, R21.2, RV21.2
24V_S2: J22.2, K22.3, R22.2, RV22.2
24V_S3: J23.2, K23.3, R23.2, RV23.2
24V_S4: J24.2, K24.3, R24.2, RV24.2
24V_S5: J25.2, K25.3, R25.2, RV25.2
24V_Supply: F2.2, J3.1
+3V3: C2.1, C4.2, C7.1, J4.2, JP1.1 (A), LED2.2 (A), R3.1, R6.1, R13.2, R14.2, TP3.1 (1_1), U1.2 (VO), U2.4, U4.2 (VDD)
+5V: C1.1, C5.1, J5.2, JP1.3 (B), K1.3, K20.5, K21.5, K22.5, K23.5, K24.5, K25.5, TP2.1 (1_1), U1.3 (VI), U3.4 (+Vout), U5.10 (COM)
/24V_On: U4.27 (IO16), U5.8 (I8)
/Coil0: K20.2, U5.12 (O7)
/Coil1: K21.2, U5.13 (O6)
/Coil2: K22.2, U5.14 (O5)
/Coil3: K23.2, U5.15 (O4)
/Coil4: K24.2, U5.16 (O3)
/Coil5: K25.2, U5.17 (O2)
/EN: C6.2, R3.2, SW1.1, U4.3 (EN)
/IO0: R6.2, SW2.1, U4.25 (IO0)
/IO1: J5.4, U4.35 (TXD0/IO1)
/IO2: LED1.2 (A), U4.24 (IO2)
/IO3: J5.3, U4.34 (RXD0/IO3)
/IO32: J4.5, R5.1, U4.8 (IO32)
/IO33: J4.6, R8.1, U4.9 (IO33)
/IO34: J4.3, R10.1, U4.6 (IO34)
/IO35: J4.4, R11.1, U4.7 (IO35)
/SCL: J6.4, R14.1, U4.26 (IO4)
/SDA: J6.3, R13.1, U4.29 (IO5)
/SSR: K1.4, U5.11 (O8)
/Sens_24V: C3.1, R2.1, U2.3, U4.10 (IO25)
/VCC_I2C: J6.2, JP1.2 (C)
/Zone0: U4.28 (IO17), U5.7 (I7)
/Zone1: U4.30 (IO18), U5.6 (I6)
/Zone2: U4.31 (IO19), U5.5 (I5)
/Zone3: U4.33 (IO21), U5.4 (I4)
/Zone4: U4.36 (IO22), U5.3 (I3)
/Zone5: U4.37 (IO23), U5.2 (I2)
GND: C1.2, C2.2, C3.2, C4.1, C5.2, C6.1, C7.2, J1.1, J4.1, J5.1, J6.1, R2.2, R4.2, R5.2, R7.2, R8.2, R9.2, R10.2, R11.2, R12.2, TP1.1 (1_1), U1.1 (GND), U3.3 (-Vout), U4.1 (GND), U4.15 (GND), U4.38 (GND), U4.39 (GND), U5.9 (GND)
L: F1.2, K1.1, RV1.1, U3.1 (AC/L)
L_SW: J2.1, K1.2, RV2.1
L_Supply: F1.1, J1.2
unnamed: C20.2, R20.1
unnamed: C21.2, R21.1
unnamed: C22.2, R22.1
unnamed: C23.2, R23.1
unnamed: C24.2, R24.1
unnamed: C25.2, R25.1
unnamed: D1.1 (K), R1.2
unnamed: LED1.1 (K), R9.1
unnamed: LED2.1 (K), R12.1
unnamed: R1.1, U2.2
unnamed: R4.1, SW1.2
unnamed: R7.1, SW2.2
Neut: J1.3, J2.2, RV1.2, RV2.2, U3.2 (AC/N)

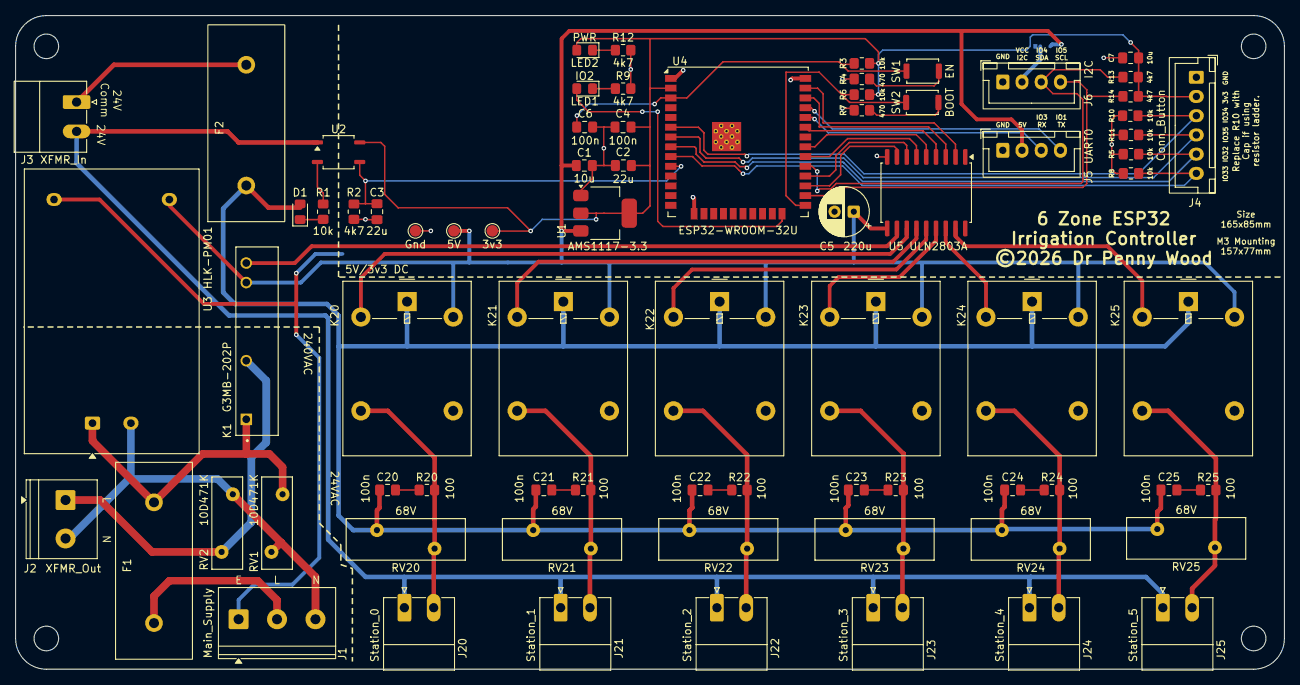
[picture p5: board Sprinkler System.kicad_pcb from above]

Board: 2 copper layers, 165.0 x 85.0 mm, 80 parts (1 on the bottom side), 55 nets.

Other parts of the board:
H1, H2, H3, H4: MountingHole_3.2mm_M3_ISO7380

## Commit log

2026-05-10 chore: initial KiCad project template
    - Directory scaffold: sheets, footprints, symbols, 3d_models, manufacturing, docs
    - .gitignore: excludes *.kicad_prl, *-backups/, lock files, fp-info-cache
    - .gitattributes: KiCad S-expression files as text/LF; 3D models as binary
    - .vscode/settings.json: file associations, Explorer filters, kicad.cliPath
    - .vscode/tasks.json: kicad-cli tasks (ERC, DRC, Gerbers, PDF, BOM, STEP, netlist)
    - .vscode/extensions.json: recommended extensions (TOML, Git Graph, GitLens)
    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
2026-05-10 Prepared Spinkler System Baseline
    [Sprinkler System.kicad_pcb, Sprinkler System.kicad_sch]
2026-05-24 Ready to Send
    [G3MB-202P.step, Sprinkler System.kicad_pcb, Sprinkler System.kicad_sch]
2026-05-31 feat: advance 6-zone sprinkler controller design and documentation
    * replace template docs with full project README (safety notes, enclosure guidance, power/control paths, wiring, BOM, GPIO map)
    * update schematic and PCB with major reannotation/layout changes, added test points, and 24 VAC net handling refinements
    * add/update project rule settings (new 24VAC net class, net class priorities, DRC exclusion updates)
    * adjust relay footprint 3D model orientation/offset
    [Sprinkler System.kicad_pcb, Sprinkler System.kicad_sch]
2026-06-03 Update PCB layout, schematic, and project config
    [Sprinkler System.kicad_pcb, Sprinkler System.kicad_sch]
2026-06-03 Manufacturing files ready for sending.
    [Sprinkler System-B_Courtyard.gbr, Sprinkler System-B_Cu.gbl, Sprinkler System-B_Fab.gbr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]
2026-06-12 Replace J1 mains connector with 5.08mm MSTBA (250V rated)
    The previous Phoenix MC 1,5/3-G-3.81 connector is only rated 160V and
    its 3.81mm pitch leaves just 2.0mm Live-to-Earth creepage at 240VAC.
    Swap to MSTBA 2,5/3-G-5,08 (project-lib copy with silkscreen clipped at
    the board edge), shift J1 up 2.5mm so the deeper body stays flush with
    the edge, re-route the L_Supply/Neut/GND stubs, move the E/L/N labels
    to the new pad pitch, and reshape the mains demarcation silk line and
    the 24V_Comm corner to preserve >=3mm mains-to-SELV spacing.
    ERC/DRC: 0 violations.
    [Sprinkler System.kicad_pcb, Sprinkler System.kicad_sch]
2026-06-13 Add 10D471K MOVs: RV1 across transformer primary, RV2 across mains input
    The G3MB-202P SSR has a built-in snubber but no overvoltage element;
    Omron requires external overvoltage protection for inductive loads.
    RV1 (L_SW-Neut) clamps the transformer-primary inductive kick at J2;
    RV2 (L-Neut, after F1) provides the HLK-PM01 datasheet-recommended
    line surge protection.
    Layout: J2 moved up 4.5mm to open space for RV1 below it (clear of the
    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
    [Sprinkler System.kicad_pcb, Sprinkler System.kicad_sch]
2026-06-13 Add C5 100nF reset capacitor on ESP32 EN
    Espressif's reference design calls for an RC delay on EN (R3 10k was
    already present, the capacitor was missing) to guarantee clean power-on
    reset as the 3V3 rail rises. Placed beside U4's EN pin, grounded via
    the existing GND via at (134.4, 57.8). Also debounces SW1.
    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
    [Sprinkler System.kicad_pcb, Sprinkler System.kicad_sch]
2026-06-13 Add C6 100nF at ESP32 VDD and C7 220uF bulk on the 5V rail
    The HLK-PM01 is rated 600mA and ESP32 WiFi TX bursts approach 500mA;
    the 5V rail previously had only 10uF of bulk. C7 (220uF radial, THT
    D6.3/P2.5) sits above U3 tapping the +5V/GND module pins on B.Cu with
    a via to the existing front-side GND run. C6 gives U4 local 3V3
    decoupling next to its VDD pin (none existed within 20mm).
    The planned third 100nF at U5 was dropped: every approach to the
    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
    [Sprinkler System.kicad_pcb, Sprinkler System.kicad_sch]
2026-06-13 Add D2 back-feed blocking diode for the UART/I2C 5V branch (DNP)
    SS34 Schottky (SMA, back side) inline in the 5V rail between the main
    supply and the J5/J6 connector branch, so an external USB-UART adapter
    on J5 can power the board but the HLK-PM01 can never back-drive the
    adapter. Marked DNP: bridge the pads (back-side silk note) until a
    Schottky is sourced - a plain silicon diode drops too much for the
    AMS1117's headroom and must not be substituted.
    The branch becomes net +5V_UART (J5 pin 2 and, until the I2C supply
    jumper lands in the next change, J6 pin 2). Zones refilled via
    kicad-cli --refill-zones.
    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
    [Sprinkler System.kicad_pcb, Sprinkler System.kicad_sch]
2026-06-13 Add JP1 solder jumper to select J6 I2C-header supply (3V3 default)
    The I2C expansion header J6 previously took the raw +5V_UART branch on
    pin 2, which would put 5V on the SDA/SCL pull-ups and any 3V3-logic
    peripheral. JP1 (3-way solder jumper on the back) selects J6's VCC:
    default-bridged 1-2 = +3V3, re-bridge 2-3 = +5V. J6 pin 2 is now the
    /J6_VCC net; J5 pin 2 keeps the true +5V_UART (re-fed from the rail on
    F.Cu past the IO-routing on the back), so UART-adapter powering and the
    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
    [Sprinkler System.kicad_pcb, Sprinkler System.kicad_sch]
2026-06-13 Fix README/ESPHome bugs and bring docs in line with the board
    Two commissioning blockers found against the netlist:
    - I2C pins were swapped: copper is SDA=GPIO5, SCL=GPIO4, but the config
    and tables said the reverse. Fixed i2c: block, GPIO table and J6 table.
    - Buttons are wired active-HIGH (10k pull-downs to GND, J4 pin2 = +3V3),
    but the config used inverted: true (active-low) so all four idled
    "pressed". Set inverted: false and documented the J4 pinout.
    Also corrected stale documentation: refdes/BOM table (U2=EL817,
    U3=HLK-PM01, U4=ESP32, U5=ULN2803A; varistors 68V; real R/C values;
    added EL817, LEDs, switches, test points); rewrote the 24 VAC sense
    section for the actual EL817 opto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
2026-06-13 Regenerate fabrication outputs for the revised board
    Re-export BOM, netlist, gerbers, drill, pick-and-place, ERC/DRC reports
    and schematic/PCB PDFs to match the schematic and PCB after this
    revision's changes (J1 connector, RV1/RV2, C5/C6/C7, D2, JP1, and the
    README/config fixes). Zones were refilled before export. ERC and DRC
    both report 0 violations.
    [Sprinkler System-B_Courtyard.gbr, Sprinkler System-B_Cu.gbl, Sprinkler System-B_Fab.gbr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]
2026-06-24 Revise board: renumber parts, drop D2, J1 to Phoenix PT 5.0mm
    Hand-edited layout changes plus regenerated fabrication outputs:
    - Renumber C/R references (EN reset now C6, +5V bulk 220uF now C5,
    ESP32 VDD decoupling C4, +3V3 10uF C7; button pull-downs R5/R8/R10/R11)
    - Remove D2 Schottky; J5 pin 2 (UART 5V) now ties directly to +5V
    - Replace J1 with Phoenix PT 1,5/3-5.0 (5.0mm, mains-rated) terminal block
    - Swap RV1/RV2 roles: RV1 across mains L-N input, RV2 across SSR output
    / transformer primary; RV footprints to stock D12mm_W4mm
    - Regenerate gerbers, drill, POS, BOM, netlist, and PDFs to match
    [Sprinkler System-B_Courtyard.gbr, Sprinkler System-B_Cu.gbl, Sprinkler System-B_Fab.gbr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]
2026-06-24 docs: sync README to renumbered board
    - Remap C/R refs in BOM and pin tables to the new numbering
    - Drop D2 Schottky description; J5 5V now ties directly to +5V
    - Swap RV1/RV2 role descriptions; J1 now Phoenix PT 5.0mm block
    - Generalise conformal-coating mask list for the new connectors
    ESPHome config and GPIO numbers were unchanged, so left as-is.
2026-06-24 Enlarge ESP32 thermal vias from 0.2mm to 0.3mm drill
    Keeps board within JLCPCB's standard 0.3mm via tier (~4x cheaper).
    Annular ring remains 0.15mm per side (0.6mm pad unchanged).
    Thermal function is unaffected — module ground is carried by perimeter pins.
    [Sprinkler System-B_Courtyard.gbr, Sprinkler System-B_Cu.gbl, Sprinkler System-B_Fab.gbr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]
2026-06-25 Remove unused folders and update .gitignore
    Deletes footprints/ (duplicate of Sprinkler System.pretty, not in fp-lib-table),
    3d_models/ and sheets/ (empty placeholders), output/ (stale DRC/quality-gate
    reports), and the empty fab/ directory. Adds manufacturing/*.zip to .gitignore.
    [G3MB-202P.step]
2026-06-25 Add 3D models for all footprints and regenerate outputs
    Adds Fuseholder_5x20mm_15mm_Pins.step and G3MB-202P.step to
    Sprinkler System.pretty so the PCB 3D viewer renders a complete board.
    Updates RELAY_G3MB-202P.kicad_mod with the corrected 3D model path.
    Regenerates docs and manufacturing exports to match.
    [Sprinkler System-B_Courtyard.gbr, Sprinkler System-B_Cu.gbl, Sprinkler System-B_Fab.gbr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]
2026-06-26 Add pre-commit hook to auto-export fabrication outputs
    Regenerates gerbers, drill, POS, STEP, PDFs, BOM, and netlist whenever
    .kicad_pcb or .kicad_sch are staged, and folds the outputs into the same
    commit. Skips gracefully if kicad-cli is not found.
    Activate with: git config core.hooksPath .githooks
2026-06-26 Stamp schematic rev field with git tag in pre-commit hook
    Uses git describe --tags --always to write the current version into the
    title_block (rev ...) field of the schematic on each commit, inserting
    the title_block section if it doesn't yet exist.
2026-06-26 Add setup and release scripts, fix hook stamp ordering
    setup: configures core.hooksPath and verifies kicad-cli is available.
    release <version>: stamps title blocks with the exact version, commits
    with KICAD_RELEASE=1 (so the hook runs exports but skips re-stamping),
    then tags. Avoids the circular dependency between git describe and the
    tagged commit.
    pre-commit: skips title block stamp when KICAD_RELEASE is set.
2026-06-26 Add title block to schematic and PCB
    [Sprinkler System-B_Courtyard.gbr, Sprinkler System-B_Cu.gbl, Sprinkler System-B_Fab.gbr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]
2026-06-26 Fix relay 3D model path for K1
    Update RELAY_G3MB-202P reference in PCB from the removed footprints/
    directory to Sprinkler System.pretty/G3MB-202P.step.
    [Sprinkler System-B_Courtyard.gbr, Sprinkler System-B_Cu.gbl, Sprinkler System-B_Fab.gbr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]
2026-06-26 docs: split README into focused reference pages
    Moves wiring tables, GPIO pinout, ESPHome config, and assembly notes
    out of the README into docs/wiring.md, docs/esphome.md, and
    docs/assembly.md. README retains the overview, safety warnings, BOM,
    and updated project structure / developing sections.
    Also updates:
    - ESPHome config: latching 24V fault with Reset button and sprinkler
    lockout, optional pump relay section for zone_0
    - Project structure: removes deleted dirs, adds new scripts and docs
    - Developing: replaces stale VS Code task docs with setup/release/hook
2026-06-26 docs: apply review corrections
    - Fix J3 connector type (screw terminal → KF2EDG pluggable)
    - Clarify resistor ladder note: GPIO34 preferred, not all four inputs
    - Fix pump relay section: use valve_master template switch to enable
    both supply_24v and pump_relay together via valve_open_switch
    - Move enclosure and conformal coating sections from README to assembly.md
2026-06-26 docs: BOM and button numbering corrections
    - Remove TP1-3 from BOM (test points, not purchaseable parts)
    - Add connectors (J1-J3, J20-J25) and external transformer to BOM
    - Renumber buttons to match J4 pin order top-to-bottom:
    Button 0=GPIO34, Button 1=GPIO35, Button 2=GPIO32, Button 3=GPIO33
2026-06-26 Add PowerShell release and setup scripts
    Windows users can now run .\setup.ps1 and .\release.ps1 directly
    from PowerShell without needing Git Bash. Shell versions remain
    for Git Bash / WSL.
2026-06-26 Release v1.0.0
    [Sprinkler System-B_Courtyard.gbr, Sprinkler System-B_Cu.gbl, Sprinkler System-B_Fab.gbr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]
2026-06-26 docs: remove JP1 from BOM (PCB feature, not a purchaseable part)

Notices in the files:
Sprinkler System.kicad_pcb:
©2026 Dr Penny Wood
